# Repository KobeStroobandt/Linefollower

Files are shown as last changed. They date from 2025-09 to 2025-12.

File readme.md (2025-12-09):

# LineFollower

lege repository die je als template kan gebruiken om een eigen repository te starten voor uw linefollower project

A description of my image


## specifications

microcontroller: ESP32 S3

motors: Aslong JGA12-N20-30

h-bridge: TB6612FNG

sensors: Polulu QTR 8

batteries: 1800 Top Fuel

wireless communication: Wifi

distance sensor - motors: 7cm

weight: 0.5 kg

speed: 0.56 m/s

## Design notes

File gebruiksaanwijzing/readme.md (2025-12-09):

# Gebruiksaanwijzing

### opladen / vervangen batterijen

1. Schakelaar aan batterij afzetten
2. Schuif de batterij uit de robot en maak de connector los
3. Nu kan je hem in het laadstation steken

---

### draadloze communicatie
---
#### verbinding maken

1. Verbind je toestel met de Wifi "KOBE-LIJNVOLGER"
2. Surf in je browser naar "192.168.4.1"
3. Op de webpagina kan je de instellingen aanpassen

---

#### commando's

- start
- stop
- speed
- calibration speed
- set kp [0..]
- set ki [0..]
- set kd [0..]
- calibrate

---

### kalibratie

1. Plaats de robot op het midden van een lijn van het parcour
2. De robot zal er nu voor zorgen dat alle sensoren eens boven de zwarte lijn komen.
3. Tijdens deze bewegingen worden de waarden die de sensor meet verwerkt en wordt de sensor gekalibreerd.

---

### settings

De robot rijdt stabiel met volgende parameters
- Kp [0.10]
- ki [0.00]
- kd [0.00]
- speed [180 of minder]
- calibration speed [50]

---

### start/stop button
De knop start en stopt de robot. 
De knop bevindt zich vanboven op de robot.

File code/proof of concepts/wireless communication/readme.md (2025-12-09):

# draadloze communicatie proof of concept
minimale hard- en software waarmee aangetoond wordt dat duplex kan gecommuniceerd worden tussen de microcontroller en een [laptop|smartphone] (schappen wat niet past), gebruik makend van Wifi (in te vullen)
<br />
### configuratie

Definiëren
```cpp
#include <WiFi.h>
#include <FS.h>
//#include <LittleFS.h>
#include <SPIFFS.h>
#include <ESPAsyncWebServer.h>
#include <AsyncTCP.h>

#define FORMAT_LITTLEFS_IF_FAILED true

const char* ssid = "KOBE-LIJNVOLGER";
const char* password = "P@ss4Kobe!";
//WiFiServer server(80);
AsyncWebServer server(80);
String header;
```
---
Wifi opstarten
```cpp
void initWifi()
{

  Serial.print("Setting AP (Access Point)…");
  WiFi.softAP(ssid, password, 6);

  IPAddress IP = WiFi.softAPIP();
  Serial.print("AP IP address: ");
  Serial.println(IP);

  // Define routes
  // Route for root / web page
  server.on("/", HTTP_GET, [](AsyncWebServerRequest *request){
    request->send(SPIFFS, "/index.html", String(), false, processor);
  });
  
  // Route to load style.css file
  server.on("/style.css", HTTP_GET, [](AsyncWebServerRequest *request){
    request->send(SPIFFS, "/style.css", "text/css");
  });

  // Start lijnvolger
  server.on("/start", HTTP_GET, [](AsyncWebServerRequest *request){
    start = true;    
    request->send(SPIFFS, "/index.html", String(), false, processor);
  });
  
  // Stop lijnvolger
  server.on("/stop", HTTP_GET, [](AsyncWebServerRequest *request){
    stop = true;    
    request->send(SPIFFS, "/index.html", String(), false, processor);
  });

  // Calibreer lijnvolger
  server.on("/calibrate", HTTP_GET, [](AsyncWebServerRequest *request){
    calibrate = true;    
    request->send(SPIFFS, "/index.html", String(), false, processor);
  });

  // Test lijnvolger
  server.on("/test", HTTP_GET, [](AsyncWebServerRequest *request){
    test = true;    
    request->send(SPIFFS, "/index.html", String(), false, processor);
  });

  // Bijwerken PID waarden <ESP_IP>/get?inputIntHigh=<inputMessage>
  server.on("/get", HTTP_GET, [] (AsyncWebServerRequest * request) {
    String inputMessage;
    // GET input value on <ESP_IP>/get?inputIntHigh=<inputMessage>
    if (request->hasParam(PARAM_P)) {
      inputMessage = request->getParam(PARAM_P)->value();
      PID_Kp = inputMessage.toFloat();
      preferences.putFloat("pid_p", PID_Kp);
    }
    // GET inputInt value on <ESP_IP>/get?inputInt=<inputMessage>
    else if (request->hasParam(PARAM_I)) {
      inputMessage = request->getParam(PARAM_I)->value();
      PID_Ki = inputMessage.toFloat();
      preferences.putFloat("pid_i", PID_Ki);
    }
    else if (request->hasParam(PARAM_D)) {
      inputMessage = request->getParam(PARAM_D)->value();
      PID_Kd = inputMessage.toFloat();
      preferences.putFloat("pid_d", PID_Kd);      
    }
    else if (request->hasParam("LFR_MAX_MOTOR_SPEED")) {
      inputMessage = request->getParam("LFR_MAX_MOTOR_SPEED")->value();
      LFR_MAX_MOTOR_SPEED = inputMessage.toInt();
      preferences.putShort("max_speed", LFR_MAX_MOTOR_SPEED);      
    }
    else if (request->hasParam("CALIBRATION_SPEED")) {
      inputMessage = request->getParam("CALIBRATION_SPEED")->value();
      CALIBRATION_SPEED = inputMessage.toInt();
      preferences.putShort("cal_speed", CALIBRATION_SPEED);      
    }
    else {
      inputMessage = "No message sent";
    }
    Serial.println(inputMessage);
    //request->send(200, "text/text", inputMessage);
    request->send(SPIFFS, "/index.html", String(), false, processor);
  });
  /*
  server.on("/temperature", HTTP_GET, [](AsyncWebServerRequest *request){
    request->send(200, "text/plain", getTemperature().c_str());
  });
  
  server.on("/humidity", HTTP_GET, [](AsyncWebServerRequest *request){
    request->send(200, "text/plain", getHumidity().c_str());
  });
  
  server.on("/pressure", HTTP_GET, [](AsyncWebServerRequest *request){
    request->send(200, "text/plain", getPressure().c_str());
  });
  */

  // Start server
  server.begin();
}
```
---
Setup
```cpp
void setup() {
  Serial.begin(115200);

  delay(2000);

  // init preferences
  preferences.begin("kobe-lijnvolger", false); 

  // Remove all preferences under the opened namespace
  //preferences.clear();

  // Read preferences
  PID_Kp           = preferences.getFloat("pid_p", PID_Kp);
  PID_Ki           = preferences.getFloat("pid_i", PID_Ki);
  PID_Kd           = preferences.getFloat("pid_d", PID_Kd);
  LFR_MAX_MOTOR_SPEED = preferences.getShort("max_speed", LFR_MAX_MOTOR_SPEED);
  CALIBRATION_SPEED   = preferences.getShort("cal_speed", CALIBRATION_SPEED);

  // configure the sensors
  qtr.setTypeRC();
  qtr.setSensorPins((const uint8_t[]){Sens01, Sens02, Sens03, Sens04, Sens05, Sens06, Sens07, Sens08}, SensorCount);
  qtr.setEmitterPin(IR);
  
  //calibrate();
  //*/

  // Initialize SPIFFS
  /*
  if (!LittleFS.begin(false)) {
    Serial.println("An Error has occurred while mounting LittleFS");
    return;
  }
    */
  if (!SPIFFS.begin(false)) {
    Serial.println("An Error has occurred while mounting Spiffs");
    return;
  } 
  
  digitalWrite(LED_BUILTIN, LOW);

 // start = true
  initWifi();
}
```
---
### opmerkingen

### gebruiksaanwijzing

verbinding maken
- Verbind je toestel met de Wifi "KOBE-LIJNVOLGER"
- Surf in je browser naar "192.168.4.1"
- Op de webpagina kan je de instellingen aanpassen

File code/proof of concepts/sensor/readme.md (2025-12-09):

# QTR-Sensoren - Proof of Concept  

Dit document beschrijft een *proof of concept* die aantoont dat:

- Bewijzen dat de ESP32 **meerdere sensoren simultaan en onafhankelijk** kan uitlezen  
- De volledige ADC-range gebruiken  
- De sensor-raw-waarden rechtstreeks tonen  

---

## Hardware Configuratie

Pinmapping:

```cpp
#include <QTRSensors.h>

#define IR 21
#define Sens01 47
#define Sens02 38
#define Sens03 39
#define Sens04 40
#define Sens05 41
#define Sens06 42
#define Sens07 2
#define Sens08 1
```

---
## Minimale Setup

```cpp
QTRSensors qtr;
const uint8_t SensorCount = 8;
uint16_t LFR_SensorValue[SensorCount];

void setup() {
  Serial.begin(115200);
  delay(1000);

  // Configureer sensoren zoals in de lijnvolger
  qtr.setTypeRC();
  qtr.setSensorPins((const uint8_t[]){
      Sens01, Sens02, Sens03, Sens04,
      Sens05, Sens06, Sens07, Sens08
  }, SensorCount);
  qtr.setEmitterPin(IR);
}
```
---
## Proof-of-Concept Loop

```cpp
void loop() {
  // Lees Ruwe sensorwaarden
  qtr.read(LFR_SensorValue);

  // Toon de waarden onafhankelijk van elkaar
  for (uint8_t i = 0; i < SensorCount; i++) {
    Serial.print(LFR_SensorValue[i]);
    Serial.print('\t');
  }
  Serial.println();

  delay(50); // snelle uitlezing voor real-time feedback
}
```
---

## Stappenplan voor demonstratie

1. ESP32 voeden via USB  
2. Seriële monitor openen op **115200 baud**  
3. Sensorarray boven wit/zwart papier bewegen  
4. Observeer:

   - Elke sensor rapporteert **een onafhankelijke ADC-waarde**  
   - Meetbereik varieert ruw tussen **0 (veel reflectie)** en **4095 (weinig reflectie)**  
   - Geen filtering, geen calibratie, pure ruwe data  

---

## Wat deze POC bewijst

Deze POC bewijst dat:

- 6+ QTR-sensoren simultaan uitgelezen kunnen worden  
- de ESP32 de volledige ADC-range benut  
- jouw pin-mapping volledig functioneel is  
- de uitlezing onafhankelijk is van PID, motorsturing of calibratie

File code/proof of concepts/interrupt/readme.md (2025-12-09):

# Hardware Interrupt Start/Stop — Proof of Concept

Dit document beschrijft een *proof of concept* die aantoont dat:

- een fysieke drukknop een hardware interrupt kan triggeren  
- de interrupt kan worden gebruikt om een start/stop functie uit te voeren  
- de lijnvolger onmiddellijk reageert op de knop
- start/stop werkt zonder polling en zonder vertraging  
  
---

## Hardware Configuratie

Pinmapping:

```cpp
#define BUTTON_PIN 4
```

Variabele:

```cpp
volatile bool hwToggle = false;
```

Interrupt Service Routine (ISR):

```cpp
void IRAM_ATTR handleButtonInterrupt() {
  hwToggle = true;
}
```

## Minimale Setup

```cpp
pinMode(BUTTON_PIN, INPUT_PULLUP);
attachInterrupt(digitalPinToInterrupt(BUTTON_PIN), handleButtonInterrupt, FALLING);
```

## Proof-of-Concept Loop

```cpp
if (hwToggle) {
  hwToggle = false;

  if (!start) {
    start = true;
    stop  = false;
    Serial.println("HW START");
  } else {
    stop  = true;
    start = false;
    Serial.println("HW STOP");
  }

  delay(200);
}
```

---

## Stappenplan voor demonstratie

1. Plaats de robot op de vloer.
   
3. Zet de ESP32 aan.
   
5. Druk op de hardware start/stop knop.
   
7. Observeer:
   - Eerste druk → lijnvolger start rijden  
   - Tweede druk → lijnvolger stopt  
   - LED of seriële output toont `HW START` / `HW STOP`  

---

## Wat deze POC bewijst

Deze POC bewijst dat:

- hardware interrupts betrouwbaar functioneren  
- een start/stop signaal correct verwerkt wordt  
- de lijnvolger direct reageert  
- de functionaliteit onafhankelijk is van WiFi-besturing

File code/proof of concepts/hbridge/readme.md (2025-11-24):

# TB6612FNG Motorcontroller – Proof of Concept

Dit document beschrijft een *proof of concept* die aantoont dat:

- Twee motoren **onafhankelijk** kunnen draaien  
- De snelheid **traploos regelbaar** is  
- De motoren eenvoudig van **draairichting** kunnen veranderen  
- De TB6612FNG motorcontroller **correct functioneert** als H-Bridge-vervanger
  
---

## Hardware Configuratie

Pinmapping:

```cpp
#define AIN1 11
#define BIN1 9
#define AIN2 12
#define BIN2 3
#define PWMA 13
#define PWMB 10
#define STBY 14
```

Motor offsets:

```cpp
const int offsetA = -1;
const int offsetB = 1;
```

Motor-objecten:

```cpp
#include <SparkFun_TB6612.h>

Motor motor1 = Motor(AIN1, AIN2, PWMA, offsetA, STBY);
Motor motor2 = Motor(BIN1, BIN2, PWMB, offsetB, STBY);
```

Maximale snelheid:

```cpp
const int MAX_SPEED = 150;
```

---

## Minimale Setup

```cpp
void setup() {
  Serial.begin(115200);
  pinMode(LED_BUILTIN, OUTPUT);
  digitalWrite(LED_BUILTIN, LOW);

  // TB6612FNG uit standby
  pinMode(STBY, OUTPUT);
  digitalWrite(STBY, HIGH);
}
```

---

## Demonstratiefuncties

### Motor vooruit / achteruit / stop

```cpp
void testForward() {
  motor1.drive(100);
  motor2.drive(100);
}

void testBackward() {
  motor1.drive(-100);
  motor2.drive(-100);
}

void testStop() {
  motor1.drive(0);
  motor2.drive(0);
}
```

### Onafhankelijke motorcontrole

```cpp
void testIndependent() {
  motor1.drive(150);   // rechts harder vooruit
  motor2.drive(50);    // links zacht vooruit
}
```

### Traploze snelheidsregeling

```cpp
void testRamp() {
  for (int s = 0; s <= MAX_SPEED; s++) {
    motor1.drive(s);
    motor2.drive(MAX_SPEED - s);
    delay(20);
  }
}
```

### Richting omdraaien

```cpp
void testDirectionChange() {
  motor1.drive(120);
  motor2.drive(120);
  delay(1000);

  motor1.drive(-120);
  motor2.drive(-120);
  delay(1000);

  testStop();
}
```

---

## Proof-of-Concept Loop

```cpp
void loop() {

  Serial.println("Vooruit");
  testForward();
  delay(1000);

  Serial.println("Achteruit");
  testBackward();
  delay(1000);

  Serial.println("Stop");
  testStop();
  delay(500);

  Serial.println("Beide motoren onafhankelijk");
  testIndependent();
  delay(1500);

  Serial.println("Traploze snelheidsregeling");
  testRamp();

  Serial.println("Omgekeerde richting");
  testDirectionChange();
}
```

---

## Stappenplan voor demonstratie

1. Sluit TB6612FNG aan volgens de hardware mapping.

2. Upload de minimale POC-code.

3. Open de Serial Monitor op 115200 baud.

4. De code doorloopt automatisch de volgende tests:

- Motoren draaien vooruit
- Motoren draaien achteruit
- Motoren stoppen
- Motoren draaien onafhankelijk met verschillende snelheden
- Traploze snelheidsverandering via testRamp()
- Richting omkeren

5. Observeer dat beide motoren zichtbaar reageren op elke testfase.

6. De demonstratie is geslaagd wanneer beide motoren:

  - afzonderlijk reageren,
  - traploos van snelheid wisselen,
  - zowel vooruit als achteruit draaien.

## Wat deze POC bewijst

| Eigenschap | Bewijs |
|---|---|
| **Onafhankelijke motorcontrole** | `motor1.drive()` en `motor2.drive()` worden apart aangestuurd |
| **Traploze snelheidsregeling** | Drive-waarden van -255 tot +255 |
| **Richting omkeerbaar** | Positieve waarde = vooruit, negatieve = achteruit |
| **TB6612FNG werkt correct** | Standby, PWM, IN1/IN2 en offsets worden gebruikt |

---

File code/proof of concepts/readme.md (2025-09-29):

# Proof of Concepts

Een proof of concept is een combinatie van minimale hard- en software om eenvoudig aan te tonen dat iets werkt.  
Proof of concepts kunnen enerzijds als eerste poging dienen om een bepaald onderdeel van het project werkend te krijgen. Anderzijds kunnen ze tijdens het debuggen van het finale project dienen als test om eventuele hardware problemen te elimineren bij onduidelijke problemen.
<br />  
<br />
Een proof of concept bestaat uit
* een elektronisch schema (indien van toepassing)
* minimale code om de voorop gestelde zaken te demonstreren
* minimale uitleg / aandachtspunten
<br />
De elektronische schakelingen van de proof of concepts komen bij voorkeur overeen met deze van de uiteindelijke linefollower, zodat de code zonder aanpassingen op het finale project kan draaien.

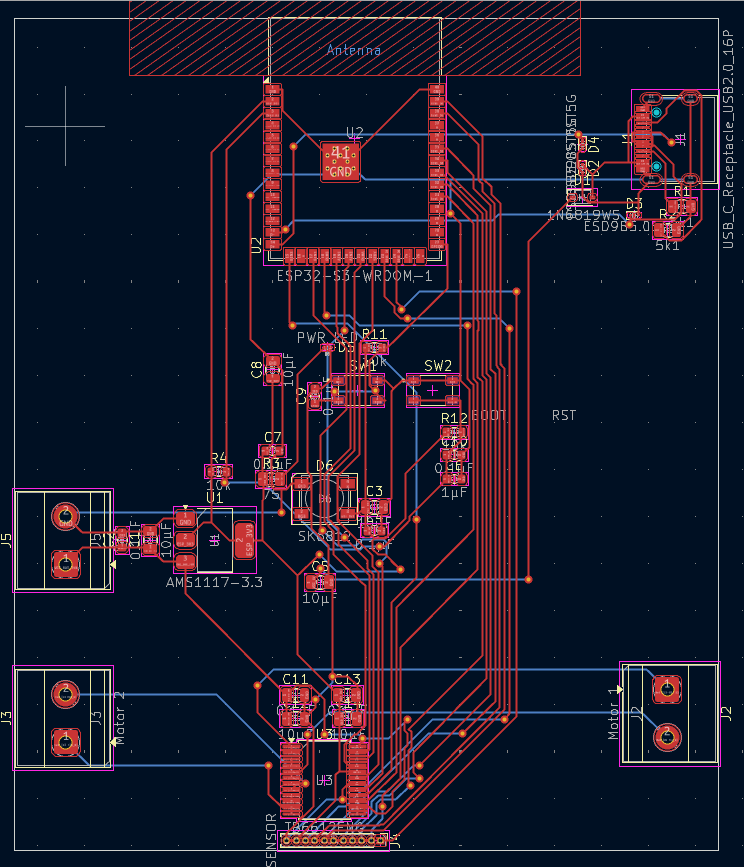
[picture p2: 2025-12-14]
technische tekeningen/elektronisch/KicadScreenshotPcb.png

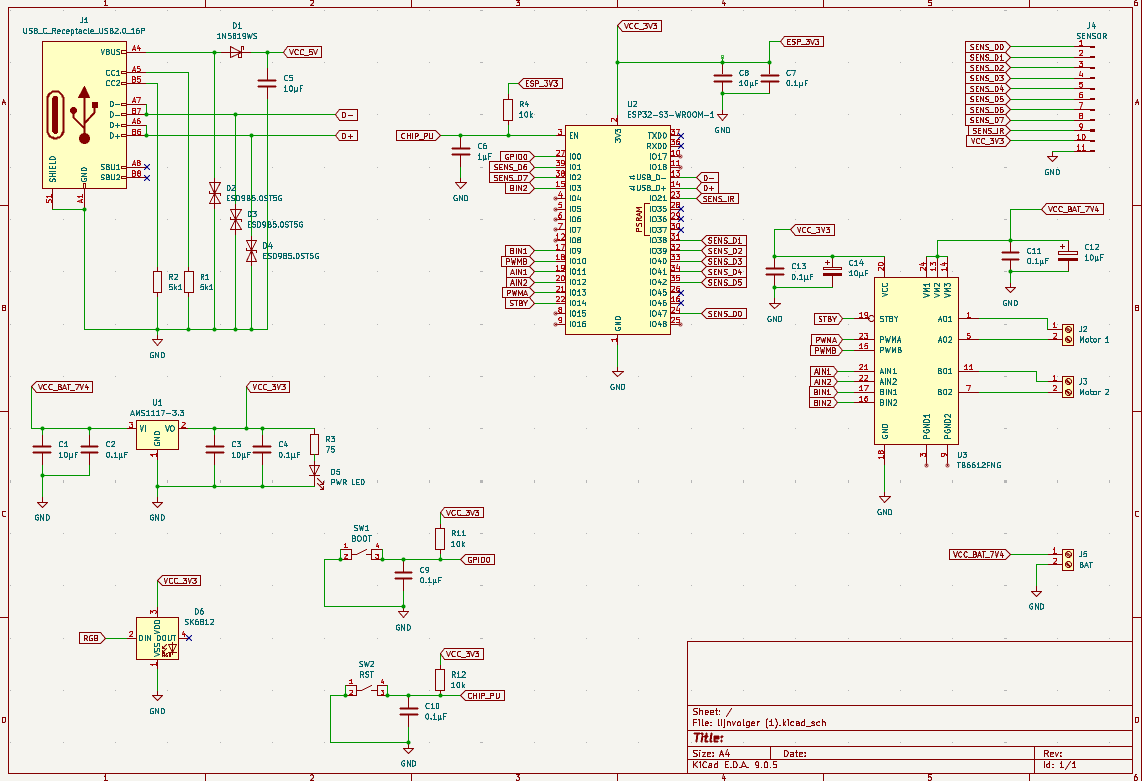
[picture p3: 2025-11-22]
technische tekeningen/elektronisch/KicadScreenshotSch.png

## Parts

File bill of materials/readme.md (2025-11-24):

## bill of materials
<br />

|volgnummer|naam|omschrijving|nieuw/recup|kostprijs/stuk|aantal|subtotaal|
|---|----|---|---|---|---|---|
| 1| SLT20 | Aluminium Siliconen Wiel 33 x 20 mm (Paar) | nieuw | €12,10 | 1 | €12,00 |
| 2| TB6612FNG | Motor controller | nieuw | €14,77 | 1 | €14,00 |
| 3| DC-DC Buck Converter | DC-DC Step-down Buck Converter 1.5A - 3.3V output | nieuw | €3,00  | 1 | €3,00  |
| 4| 1800 Top Fuel | Lipo batterij, 1800mAh, 2S/7.4V, 13,3Wh, 25C | recup | €20,00 | 1 | €20,00 |
| 5| Polulu QTR 8 | Reflectance Sensor Array | nieuw | €12,00 | 1 | €12,00 |
| 6| Aslong JGA12-N20-30  | DC-Transmissiemotor 6V - 500RPM | nieuw | €4,50  | 2 | €9,00  |
| 7| ESP32 S3 | Microcontroller met Wifi | recup | €15,00 | 1 | €15,00 |

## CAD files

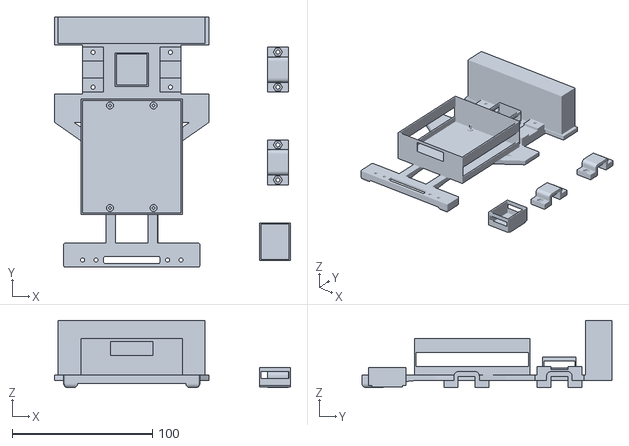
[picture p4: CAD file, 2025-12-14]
technische tekeningen/mechanisch/Lijnvolger.stl
168.0 x 178.0 x 48.0

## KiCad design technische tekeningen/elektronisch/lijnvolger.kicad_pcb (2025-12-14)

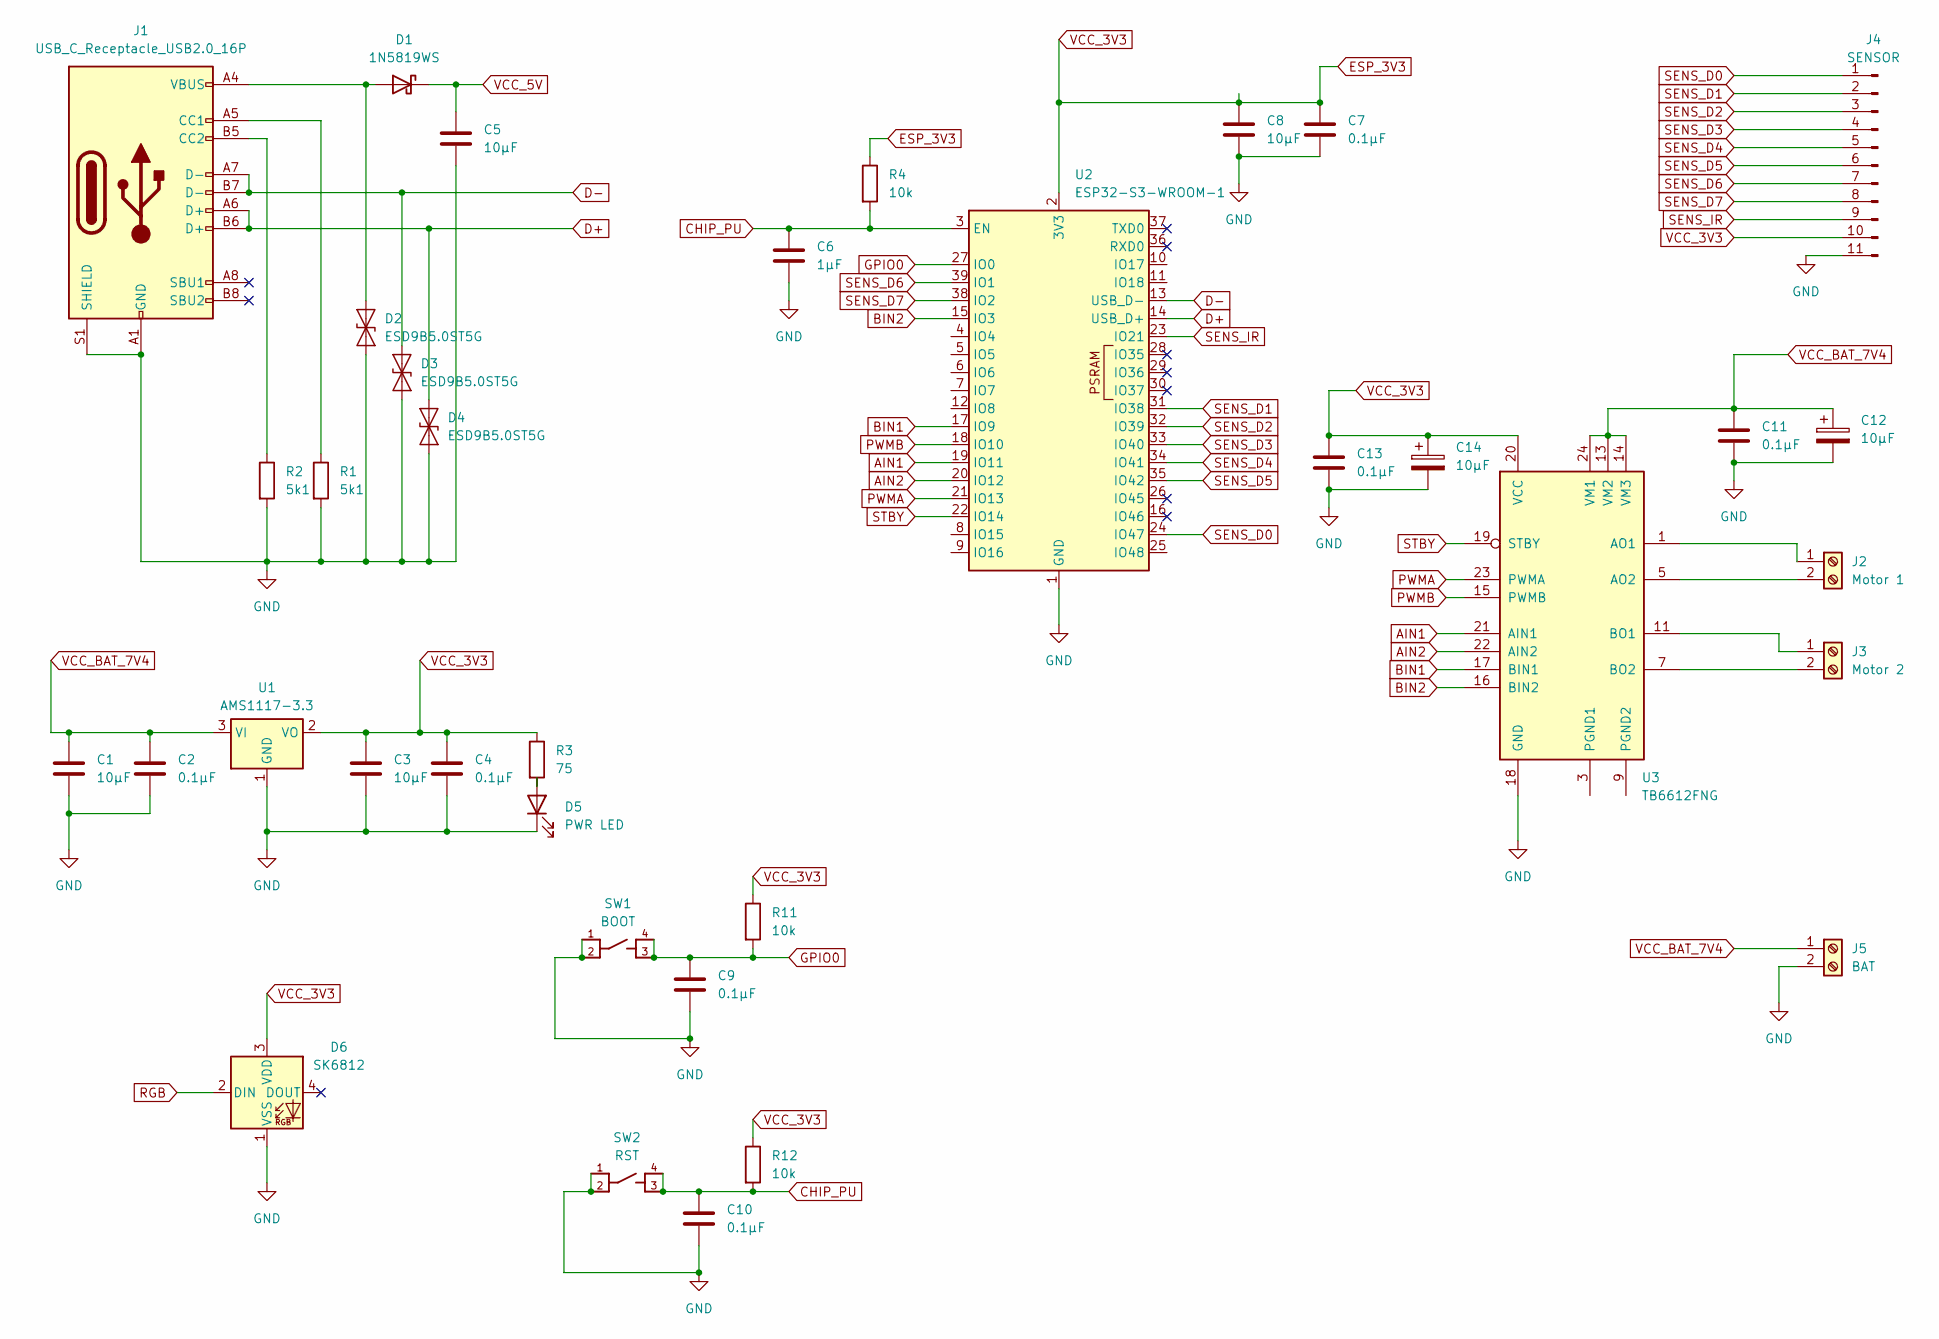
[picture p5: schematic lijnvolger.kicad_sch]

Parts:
C1, C3, C5, C8, C12, C14: 10µF; C_0805_2012Metric
C2, C4, C7, C9, C10: 0.1µF; C_0603_1608Metric
C6: 1µF; C_0603_1608Metric
C11, C13: 0.1µF; C_0805_2012Metric
D1: 1N5819WS; D_SOD-323
D2, D3, D4: ESD9B5.0ST5G; D_SOD-923
D5: PWR LED; LED_0201_0603Metric
D6: SK6812; LED_SK6812_PLCC4_5.0x5.0mm_P3.2mm
J1: USB_C_Receptacle_USB2.0_16P; USB_C_Receptacle_HRO_TYPE-C-31-M-12
J2: Motor 1; TerminalBlock_Phoenix_MKDS-1,5-2-5.08_1x02_P5.08mm_Horizont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
J3: Motor 2; TerminalBlock_Phoenix_MKDS-1,5-2-5.08_1x02_P5.08mm_Horizont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
J4: SENSOR; PinHeader_1x11_P1.00mm_Vertical
J5: BAT; TerminalBlock_Phoenix_MKDS-1,5-2-5.08_1x02_P5.08mm_Horizont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
R1, R2: 5k1; R_0805_2012Metric
R3: 75; R_0805_2012Metric
R4, R11, R12: 10k; R_0603_1608Metric
SW1: BOOT; SW_PTS810_SJM_250_SMTR_LFS
SW2: RST; SW_PTS810_SJM_250_SMTR_LFS
U1: AMS1117-3.3; SOT-223-3_TabPin2
U2: ESP32-S3-WROOM-1
U3: TB6612FNG; SSOP-24_5.3x8.2mm_P0.65mm

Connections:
AIN1: U2.19 (IO11), U3.21 (AIN1)
AIN2: U2.20 (IO12), U3.22 (AIN2)
BIN1: U2.17 (IO9), U3.17 (BIN1)
BIN2: U2.15 (IO3), U3.16 (BIN2)
CHIP_PU: C6.1, C10.1, R4.2, R12.2, SW2.3, SW2.4, U2.3 (EN)
D+: D4.1 (A1), J1.A6 (D+), J1.B6 (D+), U2.14 (USB_D+)
D-: D3.1 (A1), J1.A7 (D-), J1.B7 (D-), U2.13 (USB_D-)
ESP_3V3: C3.1, C4.1, C7.1, C8.1, C13.1, C14.1, D6.3 (VDD), J4.10, R3.1, R4.1, R11.1, R12.1, U1.2 (VO), U2.2 (3V3), U3.20 (VCC)
GND: C1.2, C2.2, C3.2, C4.2, C5.2, C6.2, C7.2, C8.2, C9.2, C10.2, C11.2, C12.2, C13.2, C14.2, D2.2 (A2), D3.2 (A2), D4.2 (A2), D5.1 (K), D6.1 (VSS), J1.A1 (GND), J1.A12 (GND), J1.B1 (GND), J1.B12 (GND), J1.S1 (SHIELD), J4.11, J5.2, R1.2, R2.2, SW1.1, SW1.2, SW2.1, SW2.2, U1.1 (GND), U2.1 (GND), U2.40 (GND), U2.41 (GND), U3.18 (GND)
GPIO0: C9.1, R11.2, SW1.3, SW1.4, U2.27 (IO0)
unnamed: D1.2 (A), D2.1 (A1), J1.A4 (VBUS), J1.A9 (VBUS), J1.B4 (VBUS), J1.B9 (VBUS)
unnamed: D5.2 (A), R3.2
unnamed: J1.A5 (CC1), R1.1
unnamed: J1.B5 (CC2), R2.1
unnamed: J2.1, U3.1 (AO1), U3.2 (AO1)
unnamed: J2.2, U3.5 (AO2), U3.6 (AO2)
unnamed: J3.1, U3.11 (BO1), U3.12 (BO1)
unnamed: J3.2, U3.7 (BO2), U3.8 (BO2)
unnamed: U3.3 (PGND1), U3.4 (PGND1)
unnamed: U3.9 (PGND2), U3.10 (PGND2)
PWMA: U2.21 (IO13), U3.23 (PWMA)
PWMB: U2.18 (IO10), U3.15 (PWMB)
RGB: D6.2 (DIN)
SENS_D0: J4.1, U2.24 (IO47)
SENS_D1: J4.2, U2.31 (IO38)
SENS_D2: J4.3, U2.32 (IO39)
SENS_D3: J4.4, U2.33 (IO40)
SENS_D4: J4.5, U2.34 (IO41)
SENS_D5: J4.6, U2.35 (IO42)
SENS_D6: J4.7, U2.39 (IO1)
SENS_D7: J4.8, U2.38 (IO2)
SENS_IR: J4.9, U2.23 (IO21)
STBY: U2.22 (IO14), U3.19 (STBY)
VCC_5V: C5.1, D1.1 (K)
VCC_BAT_7V4: C1.1, C2.1, C11.1, C12.1, J5.1, U1.3 (VI), U3.13 (VM2), U3.14 (VM3), U3.24 (VM1)

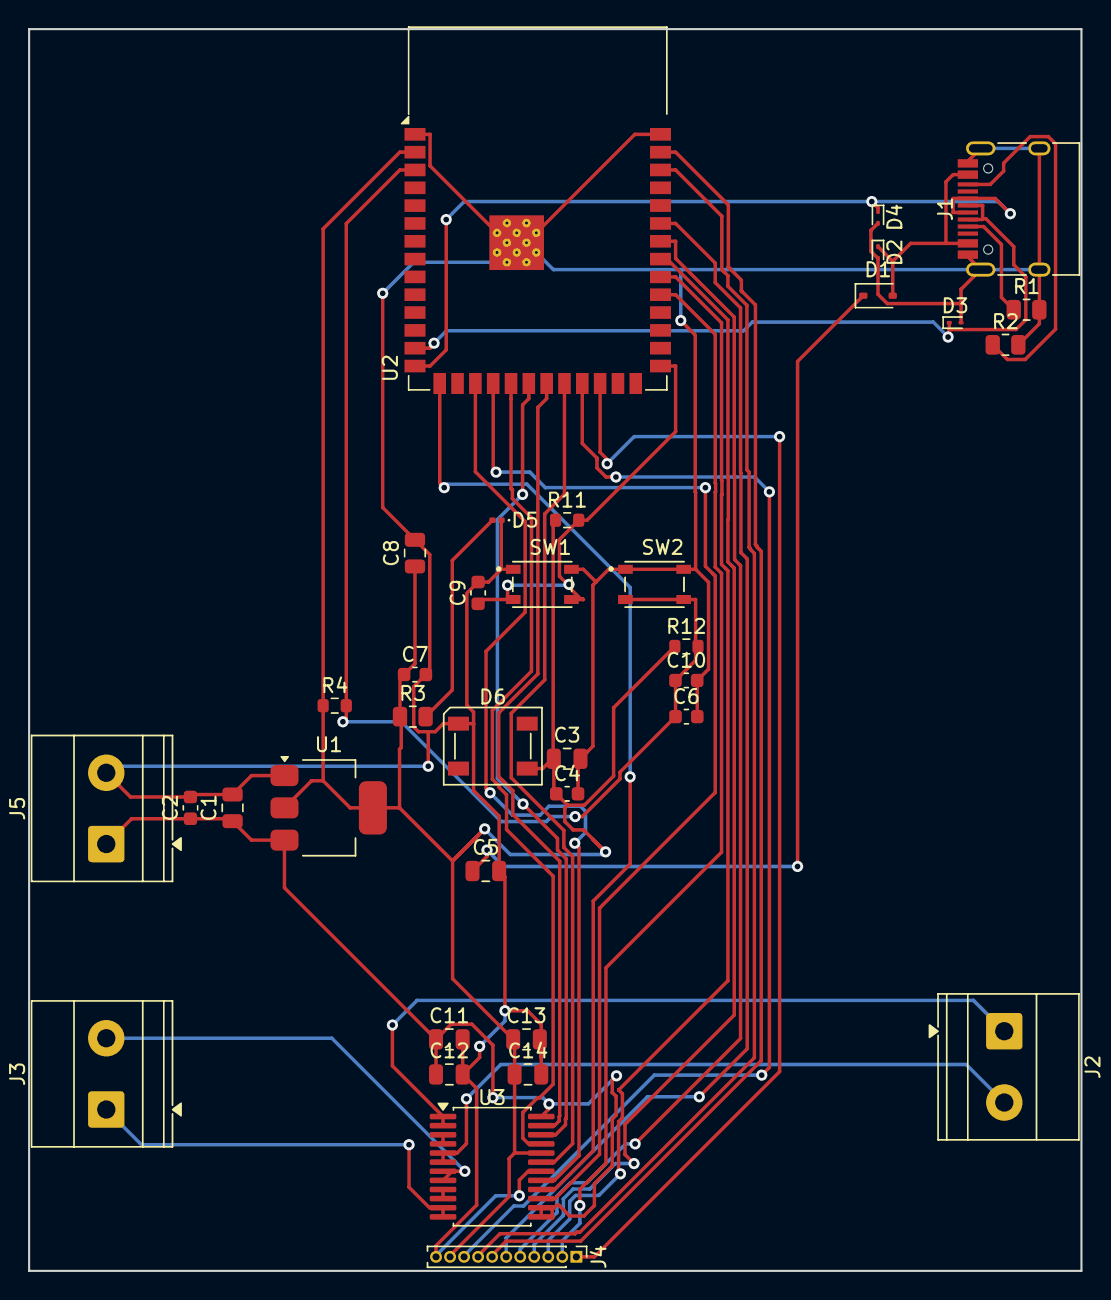
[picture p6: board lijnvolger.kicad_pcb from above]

Board: 2 copper layers, 75.0 x 88.5 mm, 36 parts (0 on the bottom side), 34 nets.

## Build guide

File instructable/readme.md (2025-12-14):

# Instructable

Een instructable is een stappenplan - zonder verdere uitleg - hoe je vertrekkend van de bill of materials en gebruik makend van de technische tekeningen de robot kan nabouwen. Ook de nodige stappen om de microcontroller te compileren en te uploaden staan beschreven.  

### stap 1
Bestel alle componenten uit de bill of materials [Link naar mijn bestand](../bill%of%materials/readme)

### stap 2
3d print nu de onderdelen voor het frame van de lijnvolger, de files vind je onder [Link naar mijn bestand](../technische%tekeningen/mechanisch)

### stap 3
Schroef nu de motoren op het frame met motor brackets

### stap 4
Schroef de sensor in de houder van het frame

### stap 5
Plaats de ESP32 in het bakje op het frame, de motor driver en de dc-dc converter hebben ook een bakje.

### stap 6
Sluit alles aan zoals aangegeven in de elektrische tekening

### stap 7
Open nu de code die terug te vinden is onder [Link naar mijn bestand](../code/finaal) in visual studio code

### stap 8
Verbind nu je PC of laptop met de ESP32 en upload de code

### stap 9
Laad de batterij op

### stap 10
Verbind de batterij met de lijnvolger

### stap 11
De robot is nu klaar voor gebruik

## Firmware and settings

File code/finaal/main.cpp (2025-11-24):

#include <Arduino.h>

/* MOTOR */
#include <SparkFun_TB6612.h>

const int offsetA = -1;
const int offsetB = 1;

#define AIN1 11
#define BIN1 9
#define AIN2 12
#define BIN2 3
#define PWMA 13
#define PWMB 10
#define STBY 14

Motor motor1 = Motor(AIN1, AIN2, PWMA, offsetA, STBY);
Motor motor2 = Motor(BIN1, BIN2, PWMB, offsetB, STBY);

// This is the maximum speed the motors will be allowed to turn.
// (400 lets the motors go at top speed; decrease to impose a speed limit)
const int MAX_SPEED = 150;


/* SENSORS */
#include <QTRSensors.h>

#define IR 21
#define Sens01 47
#define Sens02 38
#define Sens03 39
#define Sens04 40
#define Sens05 41
#define Sens06 42
#define Sens07 2
#define Sens08 1

QTRSensors qtr;

const uint8_t SensorCount = 8;
uint16_t sensorValues[SensorCount];
int lastError = 0;


/* WIFI */
#include <WiFi.h>
#include <FS.h>
//#include <LittleFS.h>
#include <SPIFFS.h>
#include <ESPAsyncWebServer.h>
#include <AsyncTCP.h>

#define FORMAT_LITTLEFS_IF_FAILED true

const char* ssid = "KOBE-LIJNVOLGER";
const char* password = "P@ss4Kobe!";
//WiFiServer server(80);
AsyncWebServer server(80);
String header;
   

/* PREFERENCES */
#include <Preferences.h>

Preferences preferences;


/* Various */
bool start = false;
bool stop = false;
bool calibrate = false;
bool test = false;

const char* PARAM_P = "inputP";
const char* PARAM_I = "inputI";
const char* PARAM_D = "inputD";

uint16_t LFR_SensorValue[8];       /**< Array to Save Raw IR Sensor values of QTR-8RC */
uint16_t LFR_Position = 0;         /**< Variable to Save the QTR-8RC Sensor Position */
int16_t  LFR_Proportional = 0;     /**< Variable to Save the Proportional Output of PID Control Algorithm */
int16_t  LFR_LastProportional = 0; /**< Variable to Save the Previous Proportional Output of PID Control Algorithm */
int16_t  LFR_Derivative = 0;      /**< Variable to Save the Derivative Output of PID Control Algorithm */
int64_t  LFR_Integral = 0;         /**< Variable to Save the Integral Output of PID Control Algorithm */
int16_t  LFR_ControlOutput = 0;    /**< Variable to Save the Final Control Output of PID Control Algorithm */
int16_t  LFR_MotorSpeedLeft = 0;
int16_t  LFR_MotorSpeedRight = 0;
int16_t  QTR_LINE_MID_VALUE = 3500;
int16_t  LFR_MAX_MOTOR_SPEED = 180; /* absolute max = 255*/
int16_t  LFR_BASE_SPEED = 100;
int16_t  CALIBRATION_SPEED = 25;
int16_t  LFR_ASYM = 40;           // tss 0 en 100, bepaalt asymmetrie bij sturen
float PID_Kp = 0.1;
float PID_Ki = 0;
float PID_Kd = 4;

/* functions */
String processor(const String& var);
void doDrive();
void doTest();
void doTestDrive();
void doTestDrive2();
void doDrive2();
void doDrive3(bool test = false);
void doOutputSensorValues();

// put function declarations here:
void doCalibrate()
{
  start = false;
  stop = false;
  calibrate = false;

  delay(500);
  pinMode(LED_BUILTIN, OUTPUT);
  digitalWrite(LED_BUILTIN, HIGH); // turn on Arduino's LED to indicate we are in calibration mode

  // 2.5 ms RC read timeout (default) * 10 reads per calibrate() call
  // = ~25 ms per calibrate() call.
  // Call calibrate() 400 times to make calibration take about 10 seconds.
  /*
  for (uint16_t i = 0; i < 400; i++)
  {
    qtr.calibrate();
  }
  */
	for(uint8_t i=0; i<40; i++)   /**< Calibrate the QTR-8RC Sensor */
	{
    motor1.drive( CALIBRATION_SPEED);
    motor2.drive(-CALIBRATION_SPEED);      /**< Rotates the Robot */
		delay(20);
    motor1.drive(0);
    motor2.drive(0);
  	qtr.calibrate();    
    delay(20);
	}
  for(uint8_t i=0; i<80; i++)   /**< Calibrate the QTR-8RC Sensor */
	{
    motor1.drive(-CALIBRATION_SPEED);
    motor2.drive( CALIBRATION_SPEED);      /**< Rotates the Robot */
		delay(20);
    motor1.drive(0);
    motor2.drive(0);
  	qtr.calibrate();    
    delay(20);
	}
  for(uint8_t i=0; i<40; i++)   /**< Calibrate the QTR-8RC Sensor */
	{
    motor1.drive( CALIBRATION_SPEED);
    motor2.drive(-CALIBRATION_SPEED);      /**< Rotates the Robot */
		delay(20);
    motor1.drive(0);
    motor2.drive(0);
  	qtr.calibrate();    
    delay(20);
	}
/*
	motor1.drive(0);          
  motor2.drive(0);
	delay(500);
	motor1.drive(-CALIBRATION_SPEED);
  motor2.drive( CALIBRATION_SPEED);      
	for(uint8_t i=0; i<80; i++)  
	{
		qtr.calibrate();  
		delay(20);
	}
	motor1.drive(0);          
  motor2.drive(0);
	delay(500);
	motor1.drive( CALIBRATION_SPEED);
  motor2.drive(-CALIBRATION_SPEED);      
	for(uint8_t i=0; i<40; i++)   
	{
		qtr.calibrate();  
		delay(20);
	}
  */
	/*
  // Auto-calibration: turn right and left while calibrating the
  // sensors.
  for(int i = 0; i < 80; i++)
  {
    if ((i > 10 && i <= 30) || (i > 50 && i <= 70))
    {
      motor1.drive(-80);
      motor2.drive( 80);
    }
    else
    {
      motor1.drive( 80);
      motor2.drive(-80);
    }
    qtr.calibrate();

    // Since our counter runs to 80, the total delay will be
    // 80*20 = 1600 ms.
    delay(20);
  }
  */

  /*
  for(int counter = 0; counter < 80; counter++)
  {
    
    if(counter < 20 || counter >= 60)
    {
      motor1.drive(-40);
      motor2.drive( 40);
    }
    else
    {
      motor1.drive( 40);
      motor2.drive(-40);
    }
    qtr.calibrate();

    // Since our counter runs to 80, the total delay will be
    // 80*20 = 1600 ms.
    delay(20);
  }
    */
  motor1.brake();
  motor2.brake();
  digitalWrite(LED_BUILTIN, LOW); // turn off Arduino's LED to indicate we are through with calibration
  delay(20);
  
  for (uint8_t i = 0; i < SensorCount; i++)
  {
    Serial.print(qtr.calibrationOn.minimum[i]);
    Serial.print(' ');
  }
  Serial.println();
  

  // print the calibration maximum values measured when emitters were on
  for (uint8_t i = 0; i < SensorCount; i++)
  {
    Serial.print(qtr.calibrationOn.maximum[i]);
    Serial.print(' ');
  }
  Serial.println();
  Serial.println();
  
  delay(1000);
}

void listDir(fs::FS &fs, const char * dirname, uint8_t levels){
    Serial.printf("Listing directory: %s\r\n", dirname);

    File root = fs.open(dirname);
    if(!root){
        Serial.println("- failed to open directory");
        return;
    }
    if(!root.isDirectory()){
        Serial.println(" - not a directory");
        return;
    }

    File file = root.openNextFile();
    while(file){
        if(file.isDirectory()){
            Serial.print("  DIR : ");
            Serial.println(file.name());
            if(levels){
                listDir(fs, file.path(), levels -1);
            }
        } else {
            Serial.print("  FILE: ");
            Serial.print(file.name());
            Serial.print("\tSIZE: ");
            Serial.println(file.size());
        }
        file = root.openNextFile();
    }
}

void initWifi()
{

  Serial.print("Setting AP (Access Point)…");
  WiFi.softAP(ssid, password, 6);

  IPAddress IP = WiFi.softAPIP();
  Serial.print("AP IP address: ");
  Serial.println(IP);


  // Define routes
  // Route for root / web page
  server.on("/", HTTP_GET, [](AsyncWebServerRequest *request){
    request->send(SPIFFS, "/index.html", String(), false, processor);
  });
  
  // Route to load style.css file
  server.on("/style.css", HTTP_GET, [](AsyncWebServerRequest *request){
    request->send(SPIFFS, "/style.css", "text/css");
  });

  // Start lijnvolger
  server.on("/start", HTTP_GET, [](AsyncWebServerRequest *request){
    start = true;    
    request->send(SPIFFS, "/index.html", String(), false, processor);
  });
  
  // Stop lijnvolger
  server.on("/stop", HTTP_GET, [](AsyncWebServerRequest *request){
    stop = true;    
    request->send(SPIFFS, "/index.html", String(), false, processor);
  });

  // Calibreer lijnvolger
  server.on("/calibrate", HTTP_GET, [](AsyncWebServerRequest *request){
    calibrate = true;    
    request->send(SPIFFS, "/index.html", String(), false, processor);
  });

  // Test lijnvolger
  server.on("/test", HTTP_GET, [](AsyncWebServerRequest *request){
    test = true;    
    request->send(SPIFFS, "/index.html", String(), false, processor);
  });

  // Bijwerken PID waarden <ESP_IP>/get?inputIntHigh=<inputMessage>
  server.on("/get", HTTP_GET, [] (AsyncWebServerRequest * request) {
    String inputMessage;
    // GET input value on <ESP_IP>/get?inputIntHigh=<inputMessage>
    if (request->hasParam(PARAM_P)) {
      inputMessage = request->getParam(PARAM_P)->value();
      PID_Kp = inputMessage.toFloat();
      preferences.putFloat("pid_p", PID_Kp);
    }
    // GET inputInt value on <ESP_IP>/get?inputInt=<inputMessage>
    else if (request->hasParam(PARAM_I)) {
      inputMessage = request->getParam(PARAM_I)->value();
      PID_Ki = inputMessage.toFloat();
      preferences.putFloat("pid_i", PID_Ki);
    }
    else if (request->hasParam(PARAM_D)) {
      inputMessage = request->getParam(PARAM_D)->value();
      PID_Kd = inputMessage.toFloat();
      preferences.putFloat("pid_d", PID_Kd);      
    }
    else if (request->hasParam("LFR_MAX_MOTOR_SPEED")) {
      inputMessage = request->getParam("LFR_MAX_MOTOR_SPEED")->value();
      LFR_MAX_MOTOR_SPEED = inputMessage.toInt();
      preferences.putShort("max_speed", LFR_MAX_MOTOR_SPEED);      
    }
    else if (request->hasParam("CALIBRATION_SPEED")) {
      inputMessage = request->getParam("CALIBRATION_SPEED")->value();
      CALIBRATION_SPEED = inputMessage.toInt();
      preferences.putShort("cal_speed", CALIBRATION_SPEED);      
    }
    else {
      inputMessage = "No message sent";
    }
    Serial.println(inputMessage);
    //request->send(200, "text/text", inputMessage);
    request->send(SPIFFS, "/index.html", String(), false, processor);
  });
  /*
  server.on("/temperature", HTTP_GET, [](AsyncWebServerRequest *request){
    request->send(200, "text/plain", getTemperature().c_str());
  });
  
  server.on("/humidity", HTTP_GET, [](AsyncWebServerRequest *request){
    request->send(200, "text/plain", getHumidity().c_str());
  });
  
  server.on("/pressure", HTTP_GET, [](AsyncWebServerRequest *request){
    request->send(200, "text/plain", getPressure().c_str());
  });
  */

  // Start server
  server.begin();
}

void setup() {
  Serial.begin(115200);

  delay(2000);

  // init preferences
  preferences.begin("kobe-lijnvolger", false); 

  // Remove all preferences under the opened namespace
  //preferences.clear();

  // Read preferences
  PID_Kp           = preferences.getFloat("pid_p", PID_Kp);
  PID_Ki           = preferences.getFloat("pid_i", PID_Ki);
  PID_Kd           = preferences.getFloat("pid_d", PID_Kd);
  LFR_MAX_MOTOR_SPEED = preferences.getShort("max_speed", LFR_MAX_MOTOR_SPEED);
  CALIBRATION_SPEED   = preferences.getShort("cal_speed", CALIBRATION_SPEED);

  // configure the sensors
  qtr.setTypeRC();
  qtr.setSensorPins((const uint8_t[]){Sens01, Sens02, Sens03, Sens04, Sens05, Sens06, Sens07, Sens08}, SensorCount);
  qtr.setEmitterPin(IR);
  
  //calibrate();
  //*/

    
  // Initialize SPIFFS
  /*
  if (!LittleFS.begin(false)) {
    Serial.println("An Error has occurred while mounting LittleFS");
    return;
  }
    */
  if (!SPIFFS.begin(false)) {
    Serial.println("An Error has occurred while mounting Spiffs");
    return;
  } 
  
  digitalWrite(LED_BUILTIN, LOW);

 // start = true
  initWifi();
}

void doStop()
{
  motor1.drive(0);
  motor2.drive(0);
  start = false;
  stop  = false;
  test  = false;
}

void doOutputSensorValues()
{
  for (uint8_t i = 0; i < SensorCount; i++)
  {
    Serial.print(LFR_SensorValue[i]);
    Serial.print('\t');
  }
  Serial.println(LFR_Position);

}

void loop() {
  if (calibrate)
  {
    doCalibrate();
  }
  else if (start && !stop)
  {
    doDrive2();
    //doDrive3(false);
  }
  else if (stop)
  {
    doStop();
  }
  else if (test)
  {
    doDrive3(true);
    //doTestDrive2();
  }
}

void doTest()
{
  // read calibrated sensor values and obtain a measure of the line position
  // from 0 to 5000 (for a white line, use readLineWhite() instead)
  uint16_t position = qtr.readLineBlack(sensorValues);

  // print the sensor values as numbers from 0 to 1000, where 0 means maximum
  // reflectance and 1000 means minimum reflectance, followed by the line
  // position
  
  for (uint8_t i = 0; i < SensorCount; i++)
  {
    Serial.print(sensorValues[i]);
    Serial.print('\t');
  }
  Serial.println(position);

  delay(250);
}

void doTestDrive()
{
  // read calibrated sensor values and obtain a measure of the line position
  // from 0 to 5000 (for a white line, use readLineWhite() instead)
  uint16_t position = qtr.readLineBlack(sensorValues);

  // print the sensor values as numbers from 0 to 1000, where 0 means maximum
  // reflectance and 1000 means minimum reflectance, followed by the line
  // position
  
  for (uint8_t i = 0; i < SensorCount; i++)
  {
    Serial.print(sensorValues[i]);
    Serial.print('\t');
  }
  Serial.println(position);


  int error = position - 3500;
  int speedDifference = error / 4 + 6 * (error - lastError);

  lastError = error;
  int m2Speed = MAX_SPEED + speedDifference;
  int m1Speed = MAX_SPEED - speedDifference;

  if (m1Speed < 0)
    m1Speed = 0;
  if (m2Speed < 0)
    m2Speed = 0;
  if (m1Speed > MAX_SPEED)
    m1Speed = MAX_SPEED;
  if (m2Speed > MAX_SPEED)
    m2Speed = MAX_SPEED;

  Serial.print(m1Speed);
  Serial.print(',');
  Serial.print(m2Speed);
  Serial.println();

  delay(250);
}

void doTestDrive2()
{
  start = false;

  LFR_Position = qtr.readLineBlack(LFR_SensorValue);    /**< Reads the QTR-8RC Line Sensor to Get the Line Position */
  LFR_Proportional = LFR_Position - QTR_LINE_MID_VALUE;             /**< Computes the Proportional Output of PID Control Algorithm */
  LFR_Derivative = LFR_Proportional - LFR_LastProportional;         /**< Computes the Derivative Output of PID Control Algorithm */
  LFR_Integral += LFR_Proportional;                                 /**< Computes the Integral Output of PID Control Algorithm */
  LFR_LastProportional = LFR_Proportional;                          /**< Saves the Old Proportional Output of PID Control Algorithm */

  LFR_ControlOutput = LFR_Proportional*PID_Kp + LFR_Integral*PID_Ki + LFR_Derivative*PID_Kd;    /**< Computes the Final Control Output of PID Control Algorithm */

  if(LFR_ControlOutput > LFR_MAX_MOTOR_SPEED)
  {
    LFR_ControlOutput = LFR_MAX_MOTOR_SPEED;    /**< Keeps The Motor Speed in Limit */
  }
  if(LFR_ControlOutput < -LFR_MAX_MOTOR_SPEED)
  {
    LFR_ControlOutput = -LFR_MAX_MOTOR_SPEED;    /**< Keeps The Motor Speed in Limit */
  }

  for (uint8_t i = 0; i < SensorCount; i++)
  {
    Serial.print(LFR_SensorValue[i]);
    Serial.print('\t');
  }
  Serial.println(LFR_Position);

  if(LFR_ControlOutput < 0)
  {
    Serial.print(LFR_MAX_MOTOR_SPEED + LFR_ControlOutput);
    Serial.print(',');
    Serial.print(LFR_MAX_MOTOR_SPEED);
    Serial.println();
  }
  else
  {
    Serial.print(LFR_MAX_MOTOR_SPEED);
    Serial.print(',');
    Serial.print(LFR_MAX_MOTOR_SPEED - LFR_ControlOutput);
    Serial.println();
  }
  delay(250);
}

void doDrive3(bool test)
{

  LFR_Position = qtr.readLineBlack(LFR_SensorValue);    /**< Reads the QTR-8RC Line Sensor to Get the Line Position */
  
  /*
  // too Right, Robot will go left
  if(LFR_Position > 3800)  
  {
      motor2.drive( LFR_BASE_SPEED);
      motor1.drive(-LFR_BASE_SPEED);
      return;    
  }

  // too Left, Robot will go right
  if(LFR_Position < 2900)
  {  
      motor2.drive( LFR_BASE_SPEED);
      motor1.drive(-LFR_BASE_SPEED);
      return;
  }
*/
  
  
  LFR_Proportional = LFR_Position - QTR_LINE_MID_VALUE;             /**< Computes the Proportional Output of PID Control Algorithm */
  LFR_Derivative = LFR_Proportional - LFR_LastProportional;         /**< Computes the Derivative Output of PID Control Algorithm */
  LFR_Integral += LFR_Proportional;                                 /**< Computes the Integral Output of PID Control Algorithm */
  LFR_LastProportional = LFR_Proportional;                          /**< Saves the Old Proportional Output of PID Control Algorithm */

  LFR_ControlOutput = LFR_Proportional*PID_Kp + LFR_Integral*PID_Ki + LFR_Derivative*PID_Kd;    /**< Computes the Final Control Output of PID Control Algorithm */

  //if (abs(LFR_ControlOutput) < 5)
  if (LFR_ControlOutput < 0)
  {
    LFR_MotorSpeedRight = LFR_BASE_SPEED + (abs(LFR_ControlOutput) * (100+LFR_ASYM) / 100);
    LFR_MotorSpeedLeft  = LFR_BASE_SPEED + (abs(LFR_ControlOutput) * (100-LFR_ASYM) / 100);
  }
  else
  {
    LFR_MotorSpeedRight = LFR_BASE_SPEED + (abs(LFR_ControlOutput) * (100-LFR_ASYM) / 100);
    LFR_MotorSpeedLeft  = LFR_BASE_SPEED + (abs(LFR_ControlOutput) * (100+LFR_ASYM) / 100);
  }

  if(LFR_MotorSpeedLeft > LFR_MAX_MOTOR_SPEED)
  {
    LFR_MotorSpeedLeft = LFR_MAX_MOTOR_SPEED;    /**< Keeps The Motor Speed in Limit */
  }
  if(LFR_MotorSpeedLeft < -LFR_MAX_MOTOR_SPEED)
  {
    LFR_MotorSpeedLeft = -LFR_MAX_MOTOR_SPEED;    /**< Keeps The Motor Speed in Limit */
  }
  if(LFR_MotorSpeedRight > LFR_MAX_MOTOR_SPEED)
  {
    LFR_MotorSpeedRight = LFR_MAX_MOTOR_SPEED;    /**< Keeps The Motor Speed in Limit */
  }
  if(LFR_MotorSpeedRight < -LFR_MAX_MOTOR_SPEED)
  {
    LFR_MotorSpeedRight = -LFR_MAX_MOTOR_SPEED;    /**< Keeps The Motor Speed in Limit */
  }

  // waarde negatief -> lijn ligt rechts -> motor links meer sturen dan motor rechts
  // waarde positief -> lijn ligt links -> ...
  // motor 2 = links
  // motor 1 = rechts

  if (test)
  {
    Serial.print("ControlOutput:");
    Serial.println(LFR_ControlOutput);
    doOutputSensorValues();
  }

  if (test)
  {
    Serial.print(LFR_MotorSpeedLeft);
    Serial.print(',');
    Serial.print(LFR_MotorSpeedRight);
    Serial.println();
  }
  else
  {
    motor1.drive(LFR_MotorSpeedLeft);
    motor2.drive(LFR_MotorSpeedRight);    /**< Drives the Motor According to the Control Output */
  }
}

void doDrive2()
{
  test = false;

  LFR_Position = qtr.readLineBlack(LFR_SensorValue);    /**< Reads the QTR-8RC Line Sensor to Get the Line Position */
  LFR_Proportional = LFR_Position - QTR_LINE_MID_VALUE;             /**< Computes the Proportional Output of PID Control Algorithm */
  LFR_Derivative = LFR_Proportional - LFR_LastProportional;         /**< Computes the Derivative Output of PID Control Algorithm */
  LFR_Integral += LFR_Proportional;                                 /**< Computes the Integral Output of PID Control Algorithm */
  LFR_LastProportional = LFR_Proportional;                          /**< Saves the Old Proportional Output of PID Control Algorithm */

  LFR_ControlOutput = LFR_Proportional*PID_Kp + LFR_Integral*PID_Ki + LFR_Derivative*PID_Kd;    /**< Computes the Final Control Output of PID Control Algorithm */

  if(LFR_ControlOutput > LFR_MAX_MOTOR_SPEED)
  {
    LFR_ControlOutput = LFR_MAX_MOTOR_SPEED;    /**< Keeps The Motor Speed in Limit */
  }
  if(LFR_ControlOutput < -LFR_MAX_MOTOR_SPEED)
  {
    LFR_ControlOutput = -LFR_MAX_MOTOR_SPEED;    /**< Keeps The Motor Speed in Limit */
  }

  if(LFR_ControlOutput < 0)
  {
    motor1.drive(LFR_MAX_MOTOR_SPEED + LFR_ControlOutput);
    motor2.drive(LFR_MAX_MOTOR_SPEED);    /**< Drives the Motor According to the Control Output */
  }
  else
  {
    motor1.drive(LFR_MAX_MOTOR_SPEED);
    motor2.drive(LFR_MAX_MOTOR_SPEED - LFR_ControlOutput);    /**< Drives the Motor According to the Control Output */
  }
}

void doDrive()
{
    test = false;

    uint16_t sensors[8];

  // Get the position of the line.  Note that we *must* provide the "sensors"
  // argument to readLine() here, even though we are not interested in the
  // individual sensor readings
  int position = qtr.readLineBlack(sensors);

  // Our "error" is how far we are away from the center of the line, which
  // corresponds to position 2500.
  int error = position - 2500;

  // Get motor speed difference using proportional and derivative PID terms
  // (the integral term is generally not very useful for line following).
  // Here we are using a proportional constant of 1/4 and a derivative
  // constant of 6, which should work decently for many Zumo motor choices.
  // You probably want to use trial and error to tune these constants for
  // your particular Zumo and line course.
  int speedDifference = error / 4 + 6 * (error - lastError);

  lastError = error;

  // Get individual motor speeds.  The sign of speedDifference
  // determines if the robot turns left or right.
  int m2Speed = MAX_SPEED + speedDifference;
  int m1Speed = MAX_SPEED - speedDifference;

  // Here we constrain our motor speeds to be between 0 and MAX_SPEED.
  // Generally speaking, one motor will always be turning at MAX_SPEED
  // and the other will be at MAX_SPEED-|speedDifference| if that is positive,
  // else it will be stationary.  For some applications, you might want to
  // allow the motor speed to go negative so that it can spin in reverse.
  if (m1Speed < 0)
    m1Speed = 0;
  if (m2Speed < 0)
    m2Speed = 0;
  if (m1Speed > MAX_SPEED)
    m1Speed = MAX_SPEED;
  if (m2Speed > MAX_SPEED)
    m2Speed = MAX_SPEED;

  motor2.drive(m1Speed);
  motor1.drive(m2Speed);
}


// Replaces placeholders in html with values
String processor(const String& var){
  //Serial.println(var);
  
  if(var == "PARAM_P"){
    return PARAM_P;
  }
  else if (var == "PARAM_I"){
    return PARAM_I;
  }
  else if (var == "PARAM_D"){
    return PARAM_D;
  }
  else if (var == "PID_Kp"){
    return (String)PID_Kp;
  }
  else if (var == "PID_Ki"){
    return (String)PID_Ki;
  }
  else if (var == "PID_Kd"){
    return (String)PID_Kd;
  }
  else if (var == "LFR_MAX_MOTOR_SPEED")
  {
    return (String)LFR_MAX_MOTOR_SPEED;
  }
  else if (var == "CALIBRATION_SPEED")
  {
    return (String)CALIBRATION_SPEED;
  }
  
  return String();
}
 

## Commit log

2025-11-03 Create BOM
2025-11-03 Update BOM
2025-11-22 Rename software.md to TB6612FNG Motorcontroller.md
2025-11-22 Rename TB6612FNG Motorcontroller.md to TB6612FNG.md
2025-12-14 Rename lijnvolger (3).kicad_sch to lijnvolger.kicad_sch
    [lijnvolger.kicad_sch]
2025-12-14 Rename lijnvolger (1).kicad_pcb to lijnvolger.kicad_pcb
    [lijnvolger.kicad_pcb]
2025-12-14 Rename Schermafbeelding 2025-12-14 203741.png to KicadScreenshotPcb.png
2025-12-14 Rename Grand Kieran-Curcan(2).stl to Lijnvolger.stl
    [Lijnvolger.stl]
